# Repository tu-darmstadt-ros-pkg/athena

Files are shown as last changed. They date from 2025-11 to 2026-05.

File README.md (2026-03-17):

# Athena

Picture of the Athena robot with four reconfigurable flippers and a 7-degree-of-freedom manipulator arm inspecting an object.

> [!note]
> This repository is still being filled.
> Lessons learned will be added soon.
> New data will be followed by a new release, so you can just watch for releases.

This repository documents the Athena rescue robot.
All required CAD and KiCAD files are available here for your reference and inspiration.
Copyright remains with the individual contributors, and commercial use is not permitted.

Athena was designed as a research robot for student projects on obstacle traversal and manipulation in rough terrain.
A whole-body crawler design enables the robot to traverse unstructured grounds without the risk of getting stuck, and
the four reconfigurable flippers enable Athena to adapt to the terrain and overcome steps of up to 41cm.
The large manipulator has a reach of up to 1.54 meters and can lift up to 2.9 kilograms at full extension and 7.2
kilograms at 0.5 meters.
With 7 degrees of freedom and 4 continuous joints with slip rings, it is extremely versatile and well-suited for
autonomous manipulation.

The environment perception modules consisting of a Livox MID-360, an Orbbec Astra Stereo S U 3 RGBD camera, and a 240°
FOV wide-angle camera enable comprehensive colored 3D environment perception.



The FOV of the individual sensors of the environment perception module

## Paper

You can find the [preprint here](https://arxiv.org/abs/2602.19898). Please cite as
```
@INPROCEEDINGS{fabian2025athena,
  author={Fabian, Stefan and Schmidt, Aljoscha and Süß, Jonas and Dishant and Oza, Aum and Von Stryk, Oskar},
  booktitle={2025 IEEE International Symposium on Safety Security Rescue Robotics (SSRR)}, 
  title={Athena: An Autonomous Open-Hardware Tracked Rescue Robot Platform}, 
  year={2025},
  pages={166-171},
  doi={10.1109/SSRR68451.2025.11391264}}
```

## CAD

The [CAD](CAD) folder contains all CAD data as Fusion archive for editing and alternatively also as STEP.
Please note that the belts are mostly visual only, and the actual belt lengths are not reflected in the model.

## Electronics

In the [electronics](electronics) folder, the custom PCBs used to distribute power and ensure safety during operation can be found.

## Remote E-Stop

The source code and bill of materials for the ~80€ remote e-stop can be found in [E-Stop](E-Stop).
This ESP32-based remote E-Stop transmits its state over BLE, ESP-NOW and LoRa for high reliability and low triggering times of up (or down) to 10ms.

## Stats

| | |
|-|-|
| Max Speed | 1.5m/s |
| Max Step Height | 41cm |
| Max manipulator reach | 1.54m  |
| Max payload @0.5m | 7.2kg  |
| Max payload @1m | 4.8kg  |
| Max payload @1.54m | 2.9kg  |

## Software

* **Motor Driver**: [athena_motor_driver](https://github.com/tu-darmstadt-ros-pkg/athena_motor_driver) provides firmware for the Teensy and ROS driver to torque-control the Unitree A1 motors. 

## Pictures

The robot Athena on the maximum step height that was tested at 41cm
<br/>
The robot Athena on 45 degree industrial metal stairs.

The robot Athena lifting a gallon and multiple water bottles totaling about 7.2kg

## Lessons learned

* [Drive](LESSONS_LEARNED_DRIVE.md)

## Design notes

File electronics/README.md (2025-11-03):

## Athena electronics

This folder contains the KiCad projects and libraries used for the custom PCBs inside Athena.

A detailed documentation for each PCB can be found inside its project folder.

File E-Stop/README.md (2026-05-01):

# ESP32 Remote E-Stop

## Overview

This repository contains the firmware, shared libraries, and ROS 2 interface for a wireless emergency stop built around the Seeed Studio XIAO ESP32S3, but any other ESP32 should work as well.
It delivers a handheld remote that broadcasts hard and soft E-Stop signals, a receiver that drives the physical safety relay, and an optional deadman switch that can be used for dangerous hardware experiments.
All nodes share a common communication stack that uses ESP-NOW and BLE for redundant, low-latency signaling.

>[!NOTE]
> This library uses [CrossTalk](https://github.com/StefanFabian/crosstalk) for host to serial communication.

## Highlights

- Dual-channel wireless transport (ESP-NOW, BLE)
- Independently latched hard E-Stop and soft E-Stop states.
- Optional deadman transmitter that triggers the hard E-Stop while enabled and not pressed and will only release while held down.
- SH1106 OLED UI on the remote with connectivity status, E-Stop indicators, and battery level.
- ROS 2 interface package for logging, visualization, and software integration with robots or tooling.

## How it works

### Components

- **Remote handset (`esp32_estop_sender_firmware`)** – Hosts the physical E-Stop, soft E-Stop, and release buttons, reads the battery voltage, and pushes state updates through `CommInterface`.
- **Receiver (`esp32_estop_receiver_firmware`)** – Listens as the Bluetooth server and ESP-Now peer, merges wireless channels, asserts the relay output on `D3`, and publishes telemetry over USB using the lightweight [CrossTalk](https://github.com/StefanFabian/crosstalk) protocol.
- **Deadman transmitter (`esp32_deadman_sender_firmware`)** _(optional)_ – Sends "active" and "triggered" states via `DeadmanCommInterface`, allowing a foot pedal or lanyard to feed into the receiver.
- **ROS 2 interface (`esp32_estop_ros` + `esp32_estop_interface`)** – Wraps the CrossTalk datastream in ROS 2 messages (`CommStatus.msg`) and exposes a `SetEnabled` service to bypass the receiver output during testing.
- **Shared firmware library (`esp32_estop_firmware_common`)** – Abstracts the radios, handles property replication, and centralizes MAC configuration inside `include/comm_interface.h`.

### Communication pipeline

1. The remote handset runs `CommInterface` in _client_ mode. Each button state is latched locally and shipped via ESP-NOW datagrams and BLE characteristics.
2. The receiver instances `CommInterface` in _server_ mode. On every update, it reads the newest packet from each transport, chooses the freshest data, and drives the relay output low (active) or high (released).
3. The optional deadman transmitter mirrors the pattern with `DeadmanCommInterface` and is OR'd into the receiver logic, so either the handheld or the deadman can trip the system.
4. Telemetry such as RSSI, link state, battery percentage, and message age are streamed to ROS 2 or any host that speaks CrossTalk over USB.

### Safety logic

- Hard E-Stop is asserted if **any** transport reports an active state or if an active deadman transmitter sees a trigger event.
- Soft E-Stop is tracked separately and can be leveraged by higher-level controllers for graceful deceleration.
- The receiver defaults to the safe state (output asserted) if no valid packets arrive within ~500 ms for the hard E-Stop.

## Hardware

### Bill of materials

| Name | Count | Url | Price | Description |
| --- | ----- | --- | --- | --- |
| Seeed XIAO ESP32S3 | 2 | <https://www.seeedstudio.com/Wio-SX1262-with-XIAO-ESP32S3-p-5982.html> | 10€ | Sender and Receiver ESP with BLE, ESP NOW. Any other ESP32 with sufficient PINs should work as well. |
| Joy-it SBC-OLED01.3 | 1 | <https://www.conrad.de/de/p/joy-it-sbc-oled01-3-display-modul-3-3-cm-1-3-zoll-128-x-64-pixel-passend-fuer-entwicklungskits-arduino-raspberry-pi-2619578.html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> | 9€ | Any 128x64 display supported by U8g2lib can be used without code modification. |
| TRU COMPONENTS Not-Aus-Schalter 3 A | 1 | <https://www.conrad.de/de/p/tru-components-not-aus-schalter-3-a-1-oeffner-ip65-1-st-2304759.html> | 14€ | |
| Samsung ICR18650 | 1 | <https://www.conrad.de/de/p/samsung-icr18650-spezial-akku-18650-kabel-li-ion-3-7-v-2600-mah-251024.html> | 9€ | Any Li-Ion should do. Other types have to be compatible with the ESP and might require a different charging board. |
| USB-C Charging Board | 1 | <https://www.amazon.de/dp/B07XG5F9T3?ref=ppx_yo2ov_dt_b_fed_asin_title> | 8€ (for 10) | Has to be compatible with battery. Note that they do not work with some smart USB-C chargers. |
| Button | 2 | <https://www.roboter-bausatz.de/p/drucktaster-button-schalter-rot-12mm-250v-1a> | 1€ | Any button should do. One for Soft E-Stop and one to release the E-Stops. |
| On-Off Switch | 1 | <https://www.conrad.com/en/p/tru-components-1587504-toggle-switch-tc-r13-66a3-02-250-v-ac-6-a-1-x-off-on-latch-1-pc-s-1587504.html> | 2€ | To toggle power from battery. |
| JST XT Connectors | Kit | <https://www.amazon.de/YIXISI-Stecker-Weiblich-Adapter-M%C3%A4nnlich/dp/B082ZLYRRN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> | 8€ | Suggested connectors to connect ESP to buttons, battery and display. |
| Breadboard | 1 | <https://www.reichelt.com/de/en/shop/product/breadboard_laminated_paper_50x100_mm-8268> | 1€ | To mount ESP32 and connectors, as well as display. |
| PETG Filament | 1 | - | 10€ | |
| **Total Cost** | | | 83€ | |

### ESP 32

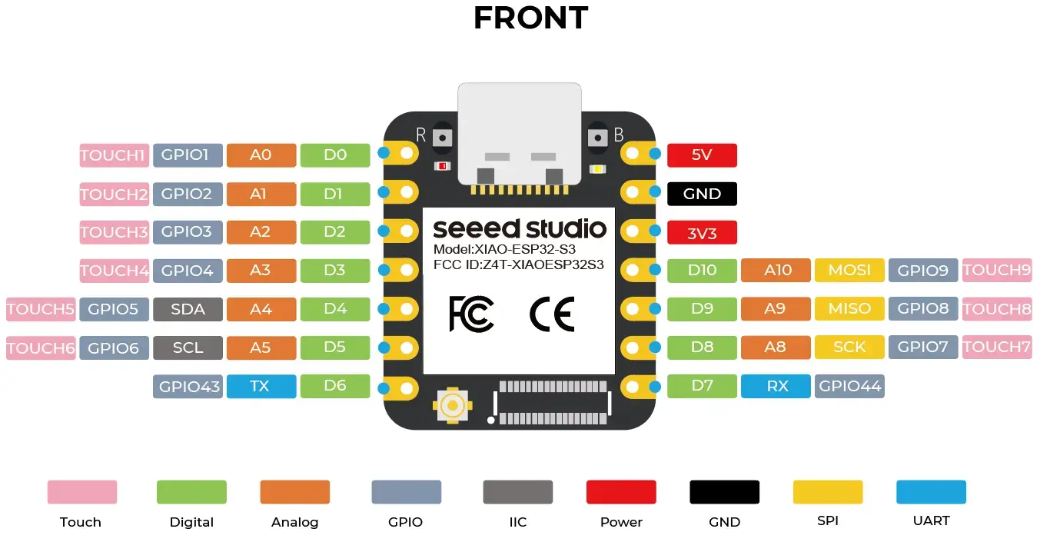
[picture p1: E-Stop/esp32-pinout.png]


#### Sender

| Pin | Function |
| --- | --- |
| D0 | _Unused_ |
| D1 | E-Stop button |
| D2 | Soft E-Stop button |
| A3 | Battery with voltage divider |
| D4, D5, D6  | Display |
| D7 | Release button |

#### Receiver

| Pin | Function |
| --- | --- |
| D3  | Low if E-Stop active, High otherwise |

### Assembly notes

- Power the receiver through the USB-C port
- The remote is powered using a battery after the separate charging board, feed the battery voltage also to `A3` using a same ratio voltage divider (e.g. 100k & 100k).
- The receiver output is an active-low digital pin; use it to drive a safety relay coil, optocoupler, or logic-level input that enforces the actual stop.

## Repository layout

| Directory | Description |
| --- | --- |
| `esp32_estop_sender_firmware/` | PlatformIO project for the handheld remote with OLED UI. |
| `esp32_estop_receiver_firmware/` | PlatformIO project for the base station / relay driver. |
| `esp32_deadman_sender_firmware/` | PlatformIO project for the optional deadman switch node. |
| `esp32_estop_firmware_common/` | Shared library with BLE, ESP-NOW, and CrossTalk helpers. |
| `esp32_estop_interface/` | ROS 2 interface definitions (messages & services). |
| `esp32_estop_ros/` | ROS 2 node that bridges the receiver to the middleware. |

## Getting started

1. **Install PlatformIO** – Either use the VS Code extension or install the CLI (`pip install platformio`).
2. **Clone the repo** – Keep the subdirectories intact so local `lib_deps` references resolve correctly.
3. **Connect the boards** – Plug each XIAO ESP32S3 via USB. The provided `platformio.ini` files expect `/dev/tty_estop_sender`, `/dev/tty_estop_receiver`, and `/dev/tty_estop_deadman_switch`; adjust them or create udev symlinks accordingly.
4. **Configure peer addresses and other settings** – See the next section to point each device at the correct MAC addresses.
5. **Build & flash** – From the respective project folder run `pio run -t upload` (or use the PlatformIO VS Code UI). Repeat for the sender, receiver, and optional deadman switch.
6. **Monitor serial output** – Use `pio device monitor` to confirm link status, RSSI, and the printed MAC addresses during bring-up.

## Configuring peer addresses

All peer MAC addresses, as well as all other relevant configuration live in `esp32_estop_firmware_common/include/config.h`:

- `RECEIVER_PEER_INFO` – The addresses for the receiver on the robot (ESP-NOW + BLE).
- `SENDER_PEER_INFO` – The remote sender's addresses.
- `DEADMAN_PEER_INFO` – The addresses for the optional deadman transmitter.

Each `CommPeerInfo` holds two 6-byte values: the ESP-NOW MAC and the BLE MAC. On the ESP32, the BLE address is typically the ESP-NOW/Wi-Fi address plus one in the least-significant byte. To adapt the system to your own hardware:

1. Flash a board with any of the firmware projects and open the serial monitor. During boot, the firmware prints the local BLE address, e.g.:

   ```text
   BLE Device initialized with address: D8:3B:DA:73:E4:30
   ```

2. Record the ESP-NOW address (`WiFi.macAddress()` if you need to query it manually) and the BLE address for each physical unit.
3. Update the corresponding `CommPeerInfo` constants in `comm_interface.h`. Keep the BLE entry consistent with the ESP-NOW address + 1 if you follow the default convention.
4. Rebuild and flash all nodes so they carry the same lookup table. A mismatch here is the most common cause of "stuck in Connecting..." on the OLED.

## Adapting to your platform

- **Different boards** – Change the `board` field in each `platformio.ini` and adjust the pin mappings to match your target carrier. The shared library is agnostic to the MCU as long as the underlying Arduino core provides ESP-NOW, NimBLE, and RadioLib support.
- **Custom user interface** – The OLED rendering lives in `esp32_estop_sender_firmware/src/main.cpp`; swap in your display driver or button layout without touching the transport layer.
- **Integrating with other controllers** – Consume the USB CrossTalk stream directly or extend the ROS 2 node (`esp32_estop_ros/src/receiver_interface_node.cpp`) to publish additional diagnostics.

## Using the system

1. Power the receiver and ensure the relay output is wired to your safety circuit.
2. Power the remote handset; the OLED shows boot progress, then "Connecting..." until at least one transport is linked.
3. Once connected, the display reports RSSI for BLE and ESP-NOW. The top banner changes to "E-Stop Active" until you press the physical release button.
4. Pressing the hard E-Stop latches the state on every transport. The receiver LED goes LOW and the relay remains asserted until the release sequence completes.
5. If the deadman transmitter is enabled, releasing its button/pedal or hitting the panic trigger instantly asserts the hard E-Stop.
6. The ROS 2 node can be launched to visualize link quality and toggle the `SetEnabled` service to disable the receiver and always enable power if needed (Note that this is dangerous!).

## Troubleshooting tips

- **No connection** – Double-check that the MAC pairs in `comm_interface.h` mirror each device’s printed addresses. A single byte mismatch prevents BLE pairing and ESP-NOW peering.
- **Relay stuck active** – Inspect the `last_received_message_age_ms` field from `CommStatus` via USB; values > 300 indicate packet loss that forces the receiver into the safe state.
- **Deadman not seen** – Verify it is enabled (LED on `D1`) and that its peer info is aligned with the receiver’s `DEADMAN_PEER_INFO` entry.

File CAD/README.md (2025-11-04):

## ATHENA CAD design

This directory contains the CAD files for the Rescue Robot ATHENA. The accompanying documentation outlines each component, its material specification, and the recommended manufacturing process.

The provided CAD model is compatible with Autodesk Fusion 360, and all components are integrated within a single comprehensive assembly file.

**Important** Before importing the model into Fusion 360, ensure that a dedicated folder is created for the project files.

## CAD Description

The primary file, main_assembly, represents the complete mechanical assembly of ATHENA. It includes all sub-assemblies and defines their kinematic and structural relationships.

Both the Flipper and Arm sub-assemblies are fully articulated within the model. They can be repositioned interactively and will automatically return to their defined resting configurations.

ATHENA consists of the following major sub-assemblies:

- sub_assembly_chassis: Composed of bonded and fastened carbon fiber composite (CFK) panels forming the primary load-bearing chassis of the robot.

- four sub_assembly_tracked_drive: Four identical tracked drive units, each integrating a drive motor, drive pulley, and flipper sub-assembly.

- two sub_assembly_battery_box: Two identical removable battery modules, each designed to accommodate a pair of 4S LiPo batteries for modular power management.

- assembly_arm_7_DoF: A 7-DoF manipulator assembly. Each joint includes predefined motion constraints, allowing spatial motion simulation and evaluation of various operational configurations.

## ATHENA Parts, Materials & Manufacturing Specification

This section lists all mechanical components of ATHENA, organized by sub-assembly. Each table specifies the part name, material, recommended manufacturing process, and additional notes.

---

## 1. Sub-Assembly: Chassis

| Part Name / ID | Material | Manufacturing Process | Notes / Remarks |
|---|---|---|---|
| base_plate | Aluminium 7075 | Laser / Plasma cutting | - |
| front_plate x2 | CFK | CNC milling / Waterjet cutting | Load bearing part, fibre arrangement should be considered |
| top_plate | CFK | CNC milling / Waterjet cutting | Load bearing part, fibre arrangement should be considered |
| side_plate | CFK | CNC milling / Waterjet cutting | Load bearing part, fibre arrangement should be considered |
| main_track_holder| CFK | CNC milling / Waterjet cutting | Load bearing part, fibre arrangement should be considered |
| CFK_angles x12 | CFK | COTS | Cut to required lengths |
| battery_box_rails| PETG | 3D printed | - |
| Flipper_motor_holder| Stainless Steel 316L| Sheet metal bending | - |
| ball_bearin_flange_20x32x7 x4| Steel | COTS | - | 
| main_track_holder_cover | GFK and PETG | Hand laminated / 3D printed| - |
| U_profile | Aluminium| COTS | - |
| M3_nut_holder  | PETG | 3D printed | - |
| Electronics holders | PETG| 3D printed | - |
| Carry_Reinforcement x4 | Steel | Laser cut | - |
| battery_box_end_plate x2 | PETG | 3D printed | - |
| sensor holders | PETG | 3D printed | - |
| flipper_motors x4 |  - | COTS | Part number: H54p-200_M54P-060 |

> **Notes:** The chassis is primarily composed of CFK components bonded and fastened to form the load-bearing frame. Maintain tight tolerances and ensure adhesive joints are properly cured. COTS: Commercial Off-The-Shelf

---

## 2. Sub-Assembly: Tracked Drive (x4)

| Part Name / ID | Material | Manufacturing Process | Notes / Remarks |
|---|---|---|---|
| Unitree A1 motor | - | COTS | [Link](https://www.unitree.com/a1/motor) |
| motor_axle_connector | Stainless Steel| CNC machined | Use high strength Loctite when mounting |
| drive_shaft | Steel | CNC machined (COTS)| Part number: KZAC20-180-NA6-NB6-TA63-KA8-HA30-KB86-HB30-KC120-HC60  [Link](https://de.misumi-ec.com/vona2/detail/110300098640/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) |
| shaft _keyway_KEG6-30| Steel | COTS | Part number: KEG6-60  [Link](https://de.misumi-ec.com/vona2/detail/110300253770/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) |
| shaft_keyway_KES6-30 x2| Steel | COTS | Part number: KES6-30 [Link](https://de.misumi-ec.com/vona2/detail/110300253770/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) |
| drive_wheel | PETG | 3D printed | Minimun 6 parameters while printing to maintain a rigid structure |
| WheelSpacer | PETG | 3D printed | - |
| FlipperSpacer  | PETG | 3D printed | - |
| ballbearing_20x42x16 | Steel | COTS | - |
| toothed_belt_pulley_48_flipper | Aluminium 7075 | CNC machined  | - |
| geared_pulley_24 | Aluminium 7075 | CNC machined | - |
| flipper_base_plate_inside | CFK | CNC machined | Load bearing part, correct fibre arrangement should be considered |
| flipper_base_plate_outside| CFK | CNC machined | Load bearing part, correct fibre arrangement should be considered |
| flippersicherung | Aluminium | Lasercut | |
|  shaft_collar_SCCJ20-6 | Steel | COTS | Part number: SCCJ20-6 [Link](https://de.misumi-ec.com/vona2/detail/110302636320/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)|
| belt_pulley_bottom | PETG and Stainless Steel 316L | 3d printed and laser cut | Two laser cut steel plates screwed and sandwiched between three 3D-printed parts |
| belt_pulley_top | PETG | 3D printed | Minimun 6 parameters while printing to maintain rigid structure |
| spacer_ARU-340 x8 | Stainless Steel | COTS | Part number: ARU-340 [Link](https://de.misumi-ec.com/vona2/detail/221006202465/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) |
| flipper_small_wheel x5| PETG | 3D printed | - |
| ballbearing_6x17x6 x10 | Steel | COTS | For flipper small wheel |
| ballbaering_flange_20x32x7 | Steel | COTS | - |
| ballbearing_flange_8x14x4 x2 | Steel | COTS | - |
| wheel spacers x3 | PETG | 3D printed | - |
| shaft_SFHRW8-49-M6-N6 | Steel | COTS | Part number: SFHRW8-49-M6-N6 [Link](https://de.misumi-ec.com/vona2/detail/110300089020/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) |
| main_track | PU with Steel reinforcement | COTS | Custom made [Link](https://www.z24.de/a/40114-zahnriemen-fuer-waschanlagen?zugtraeger=1&profil=2&quantity=1) |
| profile_mount_main_track x104| Steel | CNC machined | - |
| profileP75 x104| PT-Flex 75 | Hand Cast | Reinforced with 3D printed skeleton structure |
| flipperbelt x4 | PU with Steel reinforcement | COTS | Custom made [Link](https://www.z24.de/a/40114-zahnriemen-fuer-waschanlagen?zugtraeger=1&profil=2&quantity=1) |
| profile_mount_flipper x144 | Steel | CNC machined  | - |
| profil_flipper x144 | PT-Flex 75 | Hand Cast  | Reinforced with laser cut steel inserts |

> **Notes:** Each tracked drive unit is identical and integrates a drive motor, drive pulley, and flipper linkage. The flipper assembly interfaces directly with the tracked drive unit. Components must be lightweight yet rigid to withstand dynamic loads.

---

## 3. Sub-Assembly: Battery Box (x2)

| Part Name / ID | Material | Manufacturing Process | Notes / Remarks |
|---|---|---|---|
| battery_box | PETG | 3D printed | Support structure neccessary while printing |
| battery_box_front_plate | CFK | CNC machined/waterjet cutting | |
| latch_C-10-2 x2| Brass | COTS | Part number: C-10-2 [Link](https://de.misumi-ec.com/vona2/detail/221004914126/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) |
| battery x2 | - | COTS | Recommended: LiPo 4S, 25C, 6750 mAh |
| XT60E-F x2 | Plastic/Copper | COTS | May be replaced in fure iteration |

> **Notes:** Each battery box houses two 4S LiPo batteries and is designed for quick replacement. Use heat-resistant materials and ensure electrical insulation integrity.

---

## 4. Sub-Assembly: Arm (7-DoF Manipulator)

| Part Name / ID | Material | Manufacturing Process | Notes / Remarks |
|---|---|---|---|
| Dynamixel H54P-200_M54P-060 x3| - | COTS | [Link](https://emanual.robotis.com/docs/en/dxl/p/ph54-200-s500-r/) |
| Dynamixel H54P-100_M54P-040 x2| - | COTS | [Link](https://emanual.robotis.com/docs/en/dxl/p/ph54-100-s500-r/) |
| Dynamixel H42P-020_M42P-020 x2| - | COTS | [Link](https://emanual.robotis.com/docs/en/dxl/p/ph42-020-s300-r/) |
| FRP54-H440_ASM  | - | COTS | - |
| FRP54-I110K x2  | - | COTS | [Link](https://en.robotis.com/shop_en/item.php?it_id=902-0082-000) | 
| FRP42-I110K | - | COTS | [Link](https://en.robotis.com/shop_en/item.php?it_id=902-0083-000) |
| FRP54-H221K | - | COTS | [Link](https://en.robotis.com/shop_en/item.php?it_id=903-0223-101) |
| FRP42-H221K | - | COTS | [Link](https://en.robotis.com/shop_en/item.php?it_id=903-0237-101)
| roll_0_shaft | Aluminium 7075 | CNC turning  | Tolerances for Press fit |
| ballbearing_25x52x18 | Steel | COTS | - |
| ballbearing_housing | Aluminium 7075 | CNC machined | Tolerances for Press fit |
| slipring_pancake | - | COTS | Custom hardware |
| manipulator_base_plate | Aluminium 7075 | CNC machined | - |
| base_plate | Aluminium | Laser cut | - |
| angle_base_plate x4| Aluminium 7075 | CNC machined | - |
| base_link_joint| Aluminium 7075 | Sheet metal fabrication | - |
| LEDsHolder x2  | PETG | 3D printed | - |
| holders | PETG | 3D printed | - |
| H54_shaft_square x2 | Aluminium 7075 | CNC turning | - |
| slipring_12_way_10A/250V x3| - | COTS | - |
| motor_CFK_tube_connector x2| Aluminium 7075 | CNC machined | - |
| 6058_CFK_round_tube x2 | CFK  | CNC machined  | - |
| ballbearing_hk60 | Steel | COTS | - |
| ballbearingHolder | PETG | 3D printed | - |
| metal_connector_nut_holder x2 | PETG | 3D printed | - |
| Pitch_3_motor_connector | Titanium | SLS 3D printed | Metal tends to shrink during 3D printing |
| Pitch_5_motor_connector | Titanium | SLS 3D printed | Metal tends to shrink during 3D printing |
| H42_shaft | Steel | CNC turning | - |
| sensor_holder  | Steel | Laser cut | - |
| Sensor_torque_ATI-9105-TW-MINI45-E | - | COTS | [Link](https://www.ati-ia.com/products/ft/ft_models.aspx?id=mini45) |
| gripper_holder | PETG | 3D printed | Minimum 6 parameteres while printing and 50% infill |
| RH-P12-RN | - | COTS | [Link](https://emanual.robotis.com/docs/en/platform/rh_p12_rn/), a self developed gripper module will be implemented in a future iteration |
| gripper module holders | PETG | 3D printed | - |

> **Notes:** Each joint includes predefined angular limits and housing components. Consider mass balancing and precision machining for smooth motion and accuracy.

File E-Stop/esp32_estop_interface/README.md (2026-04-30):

# esp32_estop_interface

Messages for the esp32 based E-Stop ROS interface.

### Messages

| Type | Description |
| --- | --- |
|  |  |

### Services

| Type | Description |
| --- | --- |
|  |  |

### Actions

| Type | Description |
| --- | --- |
|  |  |

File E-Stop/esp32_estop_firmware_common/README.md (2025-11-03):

# My PlatformIO Library

## Overview
My PlatformIO Library is a shared common library designed for use in both sender and receiver projects. It provides essential functionalities that can be utilized across different applications.

## Features
- Easy integration with PlatformIO projects.
- Supports Arduino framework.
- Compatible with multiple platforms including ESP32 and Atmel AVR.

## Installation
To install the library, add the following line to your `platformio.ini` file:

```
lib_deps = yourusername/my-platformio-library
```

## Usage
Include the library in your project by adding the following line to your source files:

```cpp
#include <MyLibrary.h>
```

## Example
Here is a simple example of how to use the MyLibrary class:

```cpp
#include <MyLibrary.h>

MyLibrary myLib;

void setup() {
    myLib.begin();
}

void loop() {
    myLib.performTask();
}
```

## Contributing
Contributions are welcome! Please feel free to submit a pull request or open an issue for any suggestions or improvements.

## License
This project is licensed under the MIT License. See the LICENSE file for more details.

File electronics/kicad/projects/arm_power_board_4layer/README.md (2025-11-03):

## General description

This board serves as a carrier for the H60SB0A050NRDC DC-DC converter which is used to power the robot arm and the Wi-Fi access point.

## Connections

There is a single 33V input that connects directly to the output of the Power Distribution Board. There are two high power 24V outputs, one of which connects to the 24V input of the E-Stop board. Another low power 24V output is connected to the Wi-Fi access point.

## Communication interface

The Arm Power Board provides an I2C interface which can be used to program the DC-DC converter and read its voltages and currents. Currently this interface is unused.

## Devices on the PCB

- MIC5282-3.3YMM-TR
	- This is a 3.3V linear regulator that provides a voltage for the power LED and the I2C interface.
- H60SB0A050NRDC
	- This is a powerful programmable DC-DC converter that can output a stable 24V given a wide input range. It is even capable of producing its 24V voltage output given a lower voltage input.
    
## List of components

- Passive components
	- Resistors
		- 1x 1kΩ DIN-0204
		- 3x 4.7kΩ DIN-0204
		- 1x 10kΩ DIN-0204
		- 1x 200kΩ DIN-0204
	- Ceramic capacitors
		- 3x 100pF THT P5.0mm
		- 1x 100nF THT P5.0mm
		- 1x 1uF THT P5.0mm
		- 1x 2.2uF THT P5.0mm
		- 1x 10uF THT P5.0mm
	- Electrolytic capacitors
		- 2x 470uF THT D10.0mm P5.0mm
	- Diodes
		- 1x LED THT D3.0mm

- Connectors
	- 1x Amass XT30U-M
	- 1x Amass XT30U-F
	- 1x JST XH B2B XH-A
	- 1x JST XH B4B XH-A

- ICs
	- 1x MIC5282-3.3YMM-TR

- Other devices
	- 1x H60SB0A050NRDC

## Note

This is the only PCB currently inside the robot that still belongs to the first generation of PCBs which used THT components.

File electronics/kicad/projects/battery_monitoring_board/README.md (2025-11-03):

## General description

This PCB is used to monitor the cell voltages of two 4s LiPo batteries connected in series. This is done using an 8-channel analog digital converter which connects to each cell via a voltage divider.

## Connections

There is a 5V power input that connects to the 5V output from the Power Distribution Board. The power input is forwarded to an output connector on the PCB that allows daisy-chaining multiple boards.
The cell connectors of the two batteries are connected to the board via two five pin connectors.

## Communication interface

The Battery Monitoring Board provides an SPI interface which allows a microcontroller to read the cell voltage measurements from the analog digital converter. This interface currently connects to the Power Distribution Board.

## Devices on the PCB

- LD1117S33TR
	- This is a linear regulator that produces a 3.3V output from a 5V input. The output is used to power the analog digital converter.
- MCP3208T-CI/SL
	- This is an 8-channel analog digital converter that outputs its measurements via SPI.
    
## List of components

- Passive components
	- Resistors
		- 8x 1kΩ 0805
		- 1x 1kΩ 1206
		- 8x 22kΩ 0805
	- Ceramic capacitors
		- 3x 1uF 0805
		- 1x 10uF 0805
	- Electrolytic capacitors
		- 1x 120uF 6.3x7.7mm
	- Diodes
		- 1x LED 0805

- Connectors
	- 2x JST EH B2B EH-A
	- 3x JST XH B5B XH-A

- ICs
	- 1x LD1117S33TR
	- 1x MCP3208T-CI/SL

## Note

The two battery cell connectors on this PCB are connected in series, so that the highest pin of the first connector is directly connected to the lowest pin of the second connector. It is crucial that the main power connectors of the batteries are also connected in series externally.

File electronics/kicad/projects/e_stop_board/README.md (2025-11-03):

## General description

This PCB serves as an E-Stop that allows the main drive motors, flipper motors and arm motors to be quickly disconnected from power using electronic switches. The E-Stop can be triggered both by a physical switch and a radio remote.

## Connections and E-Stop behavior

There are three power inputs, two receiving power from the output of the Power Distribution Board providing 33V for the main drive motors and flipper motors and another input from the 24V converter for the arm motors. There are seven power outputs which connect to the motors of the robot.
- Four outputs for each of the four main drive motors
- Two outputs for the flipper motors
- One output for the robot arm
When the E-Stop is engaged, all of these outputs will be electronically disconnected from the inputs.
A connector labeled 'E-Stop' connects to the physical E-Stop button. When this button is open, the electronic switches are disabled, cutting power to the motors. Another connector with two pins labeled 'IN' and 'GND' is used to connect to the radio receiver of the remote E-Stop. There are two possible states:
- When the 'IN' pin is pulled to 3.3V relative to 'GND', the remote E-Stop is considered disengaged and the electronic switches are enabled, giving power to the motors. 
- When the 'IN' pin is floating or pulled to 'GND', the remote E-Stop is considered engaged and power is cut.
Alternatively, the remote E-Stop receiver may act as a switch itself. If this is the case, the two pins labeled 'IN -> 3.3V' on the PCB can be bridged which will pull the 'IN' pin to 3.3V unless it is pulled to 'GND' by the remote E-Stop receiver.

**Important:**
If a remote E-Stop is connected, then the pins labeled 'EN_MC' must be bridged using a jumper. If there is no remote E-stop connected, the pins labeled 'V3_3' must be bridged.

## Communication interfaces

The main communication interface of the E-Stop board is the USB connection to the STM32 NUCLEO microcontroller. This interface can be used to read the actual E-Stop state as well as the currents from the inputs to each of the outputs.
The E-Stop board also has interfaces for I2C and SPI, which can be used to communicate with the board using another microcontroller. Currently, these interfaces are unused.

## Devices on the PCB

- STM32 NUCLEO microcontroller
	- This microcontroller reads the state of the remote E-Stop and produces a signal to the switches. It also reads the current through each switch.
- BTH500151LUAAUMA1
	- These are high side power switches, that connect or disconnect the inputs and outputs. They are controlled via a digital signal from the microcontroller and output the current flowing through them using an analog voltage.

## List of components

 - Passive components
	- Resistors
		- 3x 1kΩ 0805
		- 6x 2kΩ 0805
		- 5x 4.7kΩ 0805
		- 1x 100kΩ 0805
	- Ceramic capacitors
		- 2x 1uF 0805
		- 9x 10uF 0805
	- Electrolytic capacitors
		- 1x 68uF Size 6.3x7.7mm
		- 1x 120uF Size 6.3x7.7mm
	- Diodes
		- 2x SL26PL-TP
		- 1x SS12
		- 3x LED 0805
	- Inductors
		- 1x 100uH ASPIAIG-S6055
	
- Connectors
	- 3x Amass XT30U-M
	- 7x Amass XT30U-F
	- 2x JST XH B2B XH-A
	- 1x JST XH B3B XH-A
	- 1x JST XH B5B XH-A

- ICs
	- 6x BTH500151LUAAUMA1
	- 1x LM2594MX-5.0/NOPB

- Other devices
	- STM32 NUCLEO-L432KC

## Note

This documentation refers to the second generation E-Stop board.

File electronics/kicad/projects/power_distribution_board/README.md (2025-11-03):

Important: Read section 'Caveats' below before assembling!
## General description

The Power Distribution Board (PDB) is the main PCB inside the robot and has several functions:
1. It acts as a global power switch, connecting to the physical power button to turn the entire system on or off
2. It automatically selects from one of three available power sources to power the system: two 33V batteries and a 24V power supply
3. It distributes power to the system, forwarding the input from the selected power source to other components inside the robot and additionally providing 5V and 12V power outputs through internal voltage converters
4. It monitors input source and outputs bus voltages, as well as the currents from the two batteries
5. It implements battery safety features such as cell undervoltage protection

## Connections

The PDB has two power inputs labeled BAT A and BAT B which each connect to a 33V battery and a third input labeled EXT which connects to an external 24V power supply. 
There are four main power outputs labeled OUT:
- Two of them connect to the E-Stop board, to provide power to the main drive motors and flipper motors.
- One connects to a DC-DC converter, which provides 24V for the robot arm, Wi-Fi access point and LiDARs.
- One connects to a DC-DC converter, which provides 19V for the two PCs.
A power output labeled CAP should be connected to a large bulk capacitor, which stabilizes the power bus and prevents voltage drops during switching events.
Additionally, there are four 5V outputs and three 12V outputs available. The 5V outputs power the two battery monitoring PCBs and the LED on the physical power switch. The 12V outputs power the Ethernet switch inside the robot.
The PDB connects to a physical latching power button, through a connector labeled SW HS. Closing or opening this switch turns the entire robot on or off. A second connector labeled SW LS is also available to connect the separate logic ground plane to global ground. This switch is usually just bridged directly in normal operation.

## Communication interfaces

The PDB has four communication interfaces available. The most important one is the USB connection to the Teensy 4.0 which is used to monitor the PDB using a PC inside the robot. There are also I2C, SPI and UART interfaces available. The SPI interface is currently used to communicate with two battery monitoring PCBs. Their CS pins are currently mapped to the RX and TX pins of the UART interface.

## Devices on the PCB

There are several devices and ICs used on the PDB. Here is a brief description of their functions:

- Teensy4.0 microcontroller
	- This microcontroller is the heart of the PDB, implementing the logic for source selection and switching, as well as monitoring the functions of the PDB.
- ACS72981ELRATR-200U3
	- These ICs measure the currents from the two batteries and report them to the Teensy4.0 microcontroller.
- LTC7001IMSE-TRPBF
	- These are isolated gate driver modules, used to drive the three pairs of common-source n-MOSFETS which connect the input sources to the output power bus. They are controlled via three separate enable signals from the microcontroller.
- LM2594MX-5.0/NOPB
	- This is a buck converter, converting the 33V or 24V from the input to 5V for powering the Teensy4.0 microcontroller.
- LM2594MX-12.0/NOPB
	- This buck converter provides 12V for powering the LTC7001IMSE-TRPBF gate drivers.
- RPA50S-4812SWP
	- This is a DC-DC converter providing 12V power output at 50W.
- RPA50S-4805SWP
	- This is a DC-DC converter providing 5V power output at 50W.
    
## List of components

 - Passive components
	- Resistors
		- 3x 100Ω 1206
		- 4x 1kΩ 1206
		- 2x 4.7kΩ 1206
		- 4x 10kΩ 0805
		- 13x 100kΩ 0805
	- Ceramic capacitors
		- 2x 1nF 0805
		- 2x 10nF 0805
		- 3x 100nF 0805
		- 8x 1uF 0805
		- 2x 2.2uF 0805
	- Electrolytic capacitors
		- 2x 68uF Size 6.3x7.7mm
		- 2x 100uF Size 6.3x7.7mm
		- 2x 120uF Size 6.3x7.7mm
	- Diodes
		- 3x SL26PL-TP
		- 4x LED 0805
		- 2x SS12
	- Inductors
		- 2x 100uH ASPIAIG-S6055

- Connectors
	- 3x JST XH B2B XH-A
	- 6x JST EH B2B EH-A
	- 2x JST EH B3B EH-A
	- 1x JST XH B5B XH-A
	- 5x Amass XT30U-F
	- 3x Amass XT60-M

- MOSFETs
	- 6x IRFS4010TRLPBF

- ICs
	- 2x ACS72981ELRATR-200U3
	- 3x LTC7001IMSE-TRPBF
	- 1x LM2594MX-5.0/NOPB
	- 1x LM2594MX-12.0/NOPB

- Other devices
	- 1x RPA50S-4812SWP
	- 1x RPA50S-4805SWP
	- 1x Teensy4.0

## Caveats

For the current version of the firmware on the Teensy4.0 microcontroller to work properly, two pairs of pins on the microcontroller must be connected together using external wires:
1. Connect pins 8 and 28.
2. Connect pins 9 and 27.
Pins 8 and 9 are connected through the PCB to the current sensing ICs which measure the battery currents. Unfortunately, these pins do not support reading the analog voltages generated by the ICs. Therefore they must be connected to pins 28 and 27 which do support analog inputs.

The following resistors should NOT be soldered to the PCB for normal operation:
- R3
- R6
- R9
- R18
- R19
- R25
These resistors can be used to modify the voltages on the gates of the n-MOSFETs for testing purposes. For normal operation, simply leave the solder pads of these resistors open and unconnected.

The UART interface is currently non-functional, as the RX and TX pins are connected to the CS pins of two external battery monitoring PCBs that communicate with the PDB via SPI.

## Note

This documentation refers to the second generation Power Distribution Board.

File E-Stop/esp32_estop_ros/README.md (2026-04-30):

# esp32_estop_ros

Server node to enable control and publish information from E-Stop receiver to ROS 2.

- [receiver_interface_node](#receiver_interface_node)

## `receiver_interface_node`

### Subscribed Topics

| Topic | Type | Description |
| --- | --- | --- |
|  |  |  |

### Published Topics

| Topic | Type | Description |
| --- | --- | --- |
|  |  |  |

### Services

| Service | Type | Description |
| --- | --- | --- |
|  |  |  |

### Actions

| Action | Type | Description |
| --- | --- | --- |
|  |  |  |

### Parameters

| Parameter | Type | Description |
| --- | --- | --- |
|  |  |  |

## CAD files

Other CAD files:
CAD/assembly_ATHENA v175.step
CAD/assembly_ATHENA v176.f3z

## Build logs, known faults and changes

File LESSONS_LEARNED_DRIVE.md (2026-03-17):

# Lessons Learned - Drive

## Initial Version

Due to time constraints, we, at first, tried 3D-printing track profiles from PETG.
We expected low friction, but the results were even worse than expected.
Even a 10° inclination on plywood is impossible to climb with such profiles.

The first actual version was made from PU with a shore hardness of A70.
We used [Poly 75-70, Polyurethan Shore A70](https://syntecshop.com/de/poly-75-70-polyurethan-shore-a70) and
[PT Flex 70](https://syntecshop.com/de/schnellhartendes-polyurethan-guss-gummi-shore-a-70-pt-flex-70).
They should have the same hardness, but the latter hardens more quickly than the former.
During use, unfortunately, the PT Flex profiles broke much more quickly and often than the Poly 75-70 profiles.
The profiles are made from a 3D printed skeleton for structural strength and an outer shell of PU for grip.

## 2026-03-16

Our new version replaces the 3D-printed skeleton with a steel plate to secure the screws, as the previous revision demonstrated that the profiles were ripping out of the screw holes due to the PETG not being robust enough.
The profiles are now fully PU with only a laser-cut 1mm steel plate to ensure they stay on the belt.
Additionally, we joined the two adjacent flipper profiles into a single part, which is connected at the first few mm, to limit bending when a step lands between the two profiles, improving the ability to climb steps.
The height of the flipper profiles was slightly reduced to ensure they are not in contact with the ground when not traversing unstructured terrain or climbing steps.
This improves the robot's ability to turn on the spot.

>[!NOTE]
> Do not add color to the PU, as this significantly reduces the material's resistance to wear and tear.

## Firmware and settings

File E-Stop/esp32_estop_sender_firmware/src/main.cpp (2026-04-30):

#include "comm_interface.h"
#include "mean_filter.h"
#include <Arduino.h>
#include <elapsedMillis.h>
#include <string>

#include <U8g2lib.h>

constexpr uint8_t ESTOP_PIN = D1;
constexpr uint8_t SOFT_ESTOP_PIN = D2;
constexpr uint8_t RELEASE_PIN = D7;
constexpr uint8_t BATTERY_PIN = A3;
constexpr uint8_t EXPERIMENT_VOLTAGE_INPUT_PIN = A0;
constexpr const char *TITLE = ROBOT_NAME " Remote E-Stop";

TaskHandle_t display_task_handle = nullptr;
SemaphoreHandle_t display_semaphore = nullptr;
U8G2_SH1106_128X64_NONAME_F_HW_I2C display( U8G2_R0, D6, D5, D4 );

CommInterface sender;

elapsedMillis last_print = 0;
elapsedMillis last_status_update_time = 0;
elapsedMillis last_soft_estop_update_time = 0;

bool soft_estop_button_pressed = false;
bool release_button_state = false;
bool display_initialized = false;
MeanFilter<uint32_t, 10> battery_voltage_filter;
bool experiment_running = false;

float readBatteryVoltage()
{
  battery_voltage_filter.addValue( analogRead( BATTERY_PIN ) );
  // Battery voltage is read using a voltage divider. Ratio = 4.127V / 2370
  return battery_voltage_filter.getMean() * ( 4.127f / 2370 );
}

int toBatteryPercentage( float voltage )
{
  // The percentage is calculated based on the voltage range of 3.0V (empty) to 4.2V (full).
  // The formula is: percentage = (voltage - 3.0) / (4.2 - 3.0) * 100
  if ( voltage < 3.0f ) {
    return 0; // Below minimum voltage, return 0%
  }
  if ( voltage > 4.2f ) {
    return 100; // Above maximum voltage, return 100%
  }
  return ( voltage - 3.0f ) / ( 4.2f - 3.0f ) * 100;
}

void drawBootScreen();

void updateDisplayTask( void * );

void runExperiment();

void setup()
{
  Serial.begin( 115200 );
  Serial.println( "Starting " ROBOT_NAME " E-Stop Remote..." );
  pinMode( BATTERY_PIN, INPUT );

  if ( display.begin() ) {
    display_initialized = true;
    drawBootScreen();
  } else {
    Serial.println( "Failed to initialize display!" );
  }

  sender.initialize( CommMode::CLIENT, RECEIVER_PEER_INFO );
  sender.setEStopState( true );      // Set E-Stop state to active initially
  sender.setSoftEStopState( false ); // Soft E-Stop is inactive initially

  Serial.println( "CommInterface initialized" );

  // Turn on LED
  pinMode( LED_BUILTIN, OUTPUT );
  digitalWrite( LED_BUILTIN, LOW );

  pinMode( ESTOP_PIN, INPUT_PULLDOWN );
  pinMode( SOFT_ESTOP_PIN, INPUT_PULLDOWN );
  pinMode( RELEASE_PIN, INPUT_PULLDOWN );
  pinMode( EXPERIMENT_VOLTAGE_INPUT_PIN, INPUT );

  soft_estop_button_pressed = digitalRead( SOFT_ESTOP_PIN ) == HIGH;
  release_button_state = digitalRead( RELEASE_PIN ) == HIGH;
  display_semaphore = xSemaphoreCreateMutex();
  xTaskCreatePinnedToCore( updateDisplayTask, "UpdateDisplay", 4096, nullptr, 0,
                           &display_task_handle, 0 );
}

struct DisplayStatus {
  CommStatus comm_status;
  bool estop_active;
  bool soft_estop_active;
} display_status;

constexpr int EXPERIMENT_STEPS = 1000;
struct ExperimentStatus {
  bool held_down = false;
  elapsedMillis held_time;
  int step = 0;
  bool estop_active = true;
  elapsedMillis step_time;
  int durations[EXPERIMENT_STEPS] = {};
  bool printed_results = false;
};

ExperimentStatus experiment_status;
elapsedMillis last_update_display_status;

void updateDisplay();

void updateState();

void loop()
{
  if ( !experiment_running ) {
    updateState();
  } else {
    runExperiment();
  }
  CommStatus status = sender.update();
  if ( last_update_display_status > 50 && xSemaphoreTake( display_semaphore, 10 ) ) {
    last_update_display_status = 0;
    display_status = { status, sender.getEStopState(), sender.getSoftEStopState() };
    xSemaphoreGive( display_semaphore );
  }
  vTaskDelay( 1 / portTICK_PERIOD_MS );
}

void updateState()
{
  // Read E-Stop button state. Here LOW means pressed, HIGH means not pressed
  const bool estop_state = digitalRead( ESTOP_PIN ) == LOW;
  // Read Soft E-Stop button state. Since these close the circuit when pressed, we use HIGH for pressed
  const bool soft_estop_state = digitalRead( SOFT_ESTOP_PIN ) == HIGH;
  // Read Release button state
  const bool last_release_state = release_button_state;
  release_button_state = digitalRead( RELEASE_PIN ) == HIGH;
  const bool release_button_pressed = release_button_state && !last_release_state;
  if ( release_button_pressed && !estop_state && !soft_estop_state ) {
    // If the Release button is pressed (and none of the estops are active), set E-Stop state to inactive
    sender.setEStopState( false );
    sender.setSoftEStopState( false );
    Serial.println( "Release button pressed, E-Stop and Soft E-Stop deactivated." );
  } else {
    // Only allow change to true. For release, we use the Release button
    const bool current_estop_state = sender.getEStopState();
    const bool current_soft_estop_state = sender.getSoftEStopState();
    if ( estop_state != current_estop_state || last_status_update_time > STATUS_UPDATE_INTERVAL_MS ) {
      last_status_update_time = 0;
      sender.setEStopState( sender.getEStopState() || estop_state );
    }
    if ( ( soft_estop_state && soft_estop_state != current_soft_estop_state ) ||
         last_soft_estop_update_time > SOFT_ESTOP_UPDATE_INTERVAL_MS ) {
      last_soft_estop_update_time = 0;
      sender.setSoftEStopState( sender.getSoftEStopState() || soft_estop_state );
    }
    if ( !estop_state && release_button_state && soft_estop_state ) {
      // If E-Stop is inactive and both Release and Soft E-Stop are pressed and held for 3s, start experiment
      if ( !experiment_status.held_down ) {
        experiment_status.held_down = true;
        experiment_status.held_time = 0;
      } else if ( experiment_status.held_time > 3000 && !experiment_running ) {
        uint32_t mv = analogReadMilliVolts( EXPERIMENT_VOLTAGE_INPUT_PIN );
        Serial.println( mv );
        if ( mv > 2000 ) {
          experiment_running = true;
          experiment_status.printed_results = false;
          sender.setEStopState( true );
          experiment_status.estop_active = true;
          experiment_status.step = 0;
          Serial.println( "Experiment started." );
        }
      }
    } else {
      experiment_status.held_down = false;
    }
  }
}

void updateDisplayTask( void * )
{
  while ( true ) {
    if ( !display_initialized ) {
      vTaskDelay( 500 / portTICK_PERIOD_MS );
      continue;
    }
    updateDisplay();
    vTaskDelay( 200 / portTICK_PERIOD_MS );
  }
}

bool first_connect = true;
elapsedMillis last_battery_draw_time = 0;

void drawBatteryLevel()
{
  float voltage = readBatteryVoltage();
  int percentage = toBatteryPercentage( voltage );
  const char *battery_icon = "0";
  if ( percentage >= 90 ) {
    battery_icon = "5"; // Full
  } else if ( percentage >= 70 ) {
    battery_icon = "4"; // High
  } else if ( percentage >= 50 ) {
    battery_icon = "3"; // Medium
  } else if ( percentage >= 30 ) {
    battery_icon = "2"; // Low
  } else if ( percentage >= 10 ) {
    battery_icon = "1"; // Critical
  }
  if ( percentage > 10 || last_battery_draw_time > 1000 ) {
    last_battery_draw_time = 0;
    display.setFont( u8g2_font_battery19_tn );
    display.drawStr( 119, 20, battery_icon );
  }
}

void drawBootScreen()
{
  display.clearBuffer();
  display.setFont( u8g2_font_squeezed_b7_tr );
  display.drawStr( 0, 12, TITLE );
  drawBatteryLevel();
  display.setFont( u8g2_font_logisoso16_tf );
  display.drawStr( 0, 48, "Booting..." );
  display.sendBuffer();
}

void drawCommState( int x, int y, CommState state, int latency_ms, float rssi )
{
  if ( state == CommState::ERROR ) {
    display.drawStr( x, y, "ERROR" );
    return;
  }
  if ( state == CommState::DISCONNECTED ) {
    display.drawStr( x, y, "-" );
    return;
  }
  std::string text;
  if ( latency_ms >= 0 ) {
    text = latency_ms > 999 ? ">999ms" : std::to_string( latency_ms ) + "ms";
    text += "(" + std::to_string( int( rssi ) ) + " dBm)";
  } else {
    text = std::to_string( int( rssi ) ) + " dBm";
  }
  display.drawStr( x, y, text.c_str() );
}

void updateDisplay()
{
  xSemaphoreTake( display_semaphore, portMAX_DELAY );
  DisplayStatus status = display_status;
  xSemaphoreGive( display_semaphore );
  display.clearBuffer();

  if ( experiment_running ) {
    display.setFont( u8g2_font_squeezed_b7_tr );
    display.drawStr( 0, 12, "Running Experiment" );
    display.setFont( u8g2_font_prospero_bold_nbp_tf );
    display.drawStr( 24, 32,
                     ( "Step " + std::to_string( experiment_status.step ) + " / " +
                       std::to_string( EXPERIMENT_STEPS ) )
                         .c_str() );
  } else {
    display.setFont( u8g2_font_squeezed_b7_tr );
    display.drawStr( 0, 12, TITLE );
    drawBatteryLevel();
    if ( first_connect ) {
      if ( status.comm_status.ble_state == CommState::CONNECTED ||
           status.comm_status.esp_now_state == CommState::CONNECTED ) {
        first_connect = false;
      }
      display.setFont( u8g2_font_logisoso16_tf );
      display.drawStr( 0, 48, "Connecting..." );
    } else if ( status.comm_status.ble_state == CommState::DISCONNECTED &&
                status.comm_status.esp_now_state == CommState::DISCONNECTED ) {
      display.setFont( u8g2_font_logisoso16_tf );
      display.drawStr( 0, 48, "Reconnecting..." );
    } else {
      if ( status.estop_active ) {
        display.setFont( u8g2_font_open_iconic_check_2x_t );
        display.drawStr( 0, 35, "B" );
        display.setFont( u8g2_font_prospero_bold_nbp_tf );
        display.drawStr( 24, 32, "E-Stop Active!" );
      } else if ( status.soft_estop_active ) {
        display.setFont( u8g2_font_open_iconic_check_1x_t );
        display.drawStr( 0, 32, "D" );
        display.setFont( u8g2_font_prospero_bold_nbp_tf );
        display.drawStr( 14, 32, "Soft E-Stop Active!" );
      } else {
        display.setFont( u8g2_font_open_iconic_check_2x_t );
        display.drawStr( 0, 35, "@" );
        display.setFont( u8g2_font_prospero_bold_nbp_tf );
        display.drawStr( 24, 32, "E-Stop Inactive" );
      }
    }
  }
  if ( status.comm_status.ble_state != CommState::DISCONNECTED ||
       status.comm_status.esp_now_state != CommState::DISCONNECTED ) {
    display.setFont( u8g2_font_minuteconsole_tr );
    display.drawStr( 2, 48, "BLE" );
    drawCommState( 0, 60, status.comm_status.ble_state, status.comm_status.ble_latency_ms,
                   status.comm_status.ble_rssi );
    display.drawStr( 66, 48, "ESP-NOW" );
    drawCommState( 64, 60, status.comm_status.esp_now_state, status.comm_status.esp_now_latency_ms,
                   status.comm_status.esp_now_rssi );
  }
  display.sendBuffer();
}

void runExperiment()
{
  if ( experiment_status.step >= EXPERIMENT_STEPS ) {
    if ( !experiment_status.printed_results ) {
      experiment_status.printed_results = true;
      experiment_status.step_time = 0;
      xSemaphoreTake( display_semaphore, portMAX_DELAY );
      display.clearBuffer();
      display.setFont( u8g2_font_squeezed_b7_tr );
      display.drawStr( 0, 12, "Results" );
      display.setFont( u8g2_font_prospero_bold_nbp_tf );
      int sum = 0;
      Serial.println( "Experiment durations (s):" );
      for ( int i = 0; i < EXPERIMENT_STEPS; i++ ) {
        Serial.print( experiment_status.durations[i] );
        Serial.print( ", " );
        sum += experiment_status.durations[i] * 10;
      }
      Serial.println();
      int mean = sum / EXPERIMENT_STEPS;
      int var_sum = 0;
      for ( int i = 0; i < EXPERIMENT_STEPS; i++ ) {
        int diff = experiment_status.durations[i] * 10 - mean;
        var_sum += diff * diff;
      }
      float stddev = sqrt( static_cast<float>( var_sum ) / EXPERIMENT_STEPS );
      char buffer[64];
      sprintf( buffer, "Avg: %.1f +- %.1f", mean / 10.0f, stddev / 10.0f );
      display.drawStr( 24, 32, buffer );
      display.sendBuffer();
    }
    if ( experiment_status.step_time > 20000 ) {
      xSemaphoreGive( display_semaphore );
      experiment_running = false;
    }
    return;
  }
  uint32_t val = analogReadMilliVolts( EXPERIMENT_VOLTAGE_INPUT_PIN );
  // Serial.println(val);
  if ( experiment_status.estop_active ) {
    if ( val < 500 ) {
      experiment_status.step_time = 0;
      sender.setEStopState( false );
      last_status_update_time = 0;
      experiment_status.estop_active = false;
    }
  } else if ( val > 1500 ) {
    sender.setEStopState( true );
    last_status_update_time = 0;
    experiment_status.estop_active = true;
    experiment_status.durations[experiment_status.step] = experiment_status.step_time;
    experiment_status.step++;
  }
  if ( last_status_update_time > 50 ) {
    sender.setEStopState( experiment_status.estop_active );
    last_status_update_time = 0;
  }
}

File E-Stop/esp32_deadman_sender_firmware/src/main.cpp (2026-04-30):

#include "deadman_comm_interface.h"
#include <Arduino.h>
#include <elapsedMillis.h>

#define ENABLED_PIN D10
#define DEADMAN_PIN D8
#define PANIC_TRIGGER_PIN D7
#define CONNECTED_LED_PIN D1
#define ACTIVE_LED_PIN D2
#define INACTIVE_LED_PIN D3

DeadmanCommInterface sender;

elapsedMillis last_print = 0;

void setup()
{
  Serial.begin( 115200 );
  Serial.println( "Starting " ROBOT_NAME " Deadman Switch..." );

  sender.initialize( RECEIVER_PEER_INFO );
  sender.setActive( false );
  sender.setTriggered( false );

  Serial.println( "CommInterface initialized" );

  // Turn on LED
  pinMode( LED_BUILTIN, OUTPUT );
  digitalWrite( LED_BUILTIN, LOW );

  pinMode( ENABLED_PIN, INPUT_PULLDOWN );
  pinMode( DEADMAN_PIN, INPUT_PULLDOWN );
  pinMode( PANIC_TRIGGER_PIN, INPUT_PULLDOWN );
  pinMode( INACTIVE_LED_PIN, OUTPUT );
  pinMode( ACTIVE_LED_PIN, OUTPUT );
  pinMode( CONNECTED_LED_PIN, OUTPUT );
  digitalWrite( INACTIVE_LED_PIN, LOW );
  digitalWrite( ACTIVE_LED_PIN, LOW );
  digitalWrite( CONNECTED_LED_PIN, LOW );
}

struct {
  bool enabled;
  bool triggered;
  bool panic_triggered;
} State;

elapsedMillis last_send = 0;

void loop()
{
  const bool enabled_state = digitalRead( ENABLED_PIN ) == HIGH;
  const bool deadman_state = digitalRead( DEADMAN_PIN ) == HIGH;
  const bool panic_trigger_state = digitalRead( PANIC_TRIGGER_PIN ) == HIGH;

  CommStatus status = sender.update();

  if ( status.esp_now_state == CommState::CONNECTED || status.ble_state == CommState::CONNECTED ) {
    digitalWrite( CONNECTED_LED_PIN, HIGH );
  } else {
    digitalWrite( CONNECTED_LED_PIN, LOW );
  }

  if ( enabled_state != State.enabled ) {
    State.enabled = enabled_state;
    sender.setActive( State.enabled );
    if ( State.enabled ) {
      Serial.println( "Deadman Switch Enabled" );
    } else {
      Serial.println( "Deadman Switch Disabled" );
      digitalWrite( INACTIVE_LED_PIN, LOW );
    }
  }
  if ( !State.enabled ) {
    digitalWrite( ACTIVE_LED_PIN, LOW );
    digitalWrite( INACTIVE_LED_PIN, LOW );
    // Send periodic update even if state hasn't changed
    if ( last_send > 100 ) {
      last_send = 0;
      sender.setActive( State.enabled );
    }
  } else {
    const bool triggered = !deadman_state || panic_trigger_state || State.panic_triggered;
    if ( last_send > 100 || triggered != State.triggered ) {
      last_send = 0;
      State.triggered = triggered;
      sender.setTriggered( State.triggered );
      if ( State.triggered ) {
        digitalWrite( ACTIVE_LED_PIN, HIGH );
        digitalWrite( INACTIVE_LED_PIN, LOW );
      } else {
        digitalWrite( ACTIVE_LED_PIN, LOW );
        digitalWrite( INACTIVE_LED_PIN, HIGH );
      }
    }

    if ( panic_trigger_state != State.panic_triggered && State.panic_triggered != deadman_state ) {
      // Can only reset panic trigger if deadman button is also released
      State.panic_triggered = panic_trigger_state;
      if ( State.panic_triggered ) {
        Serial.println( "Panic Triggered" );
      } else {
        Serial.println( "Panic Released" );
      }
    }
  }

  if ( last_print > 2000 ) {
    last_print = 0;
    Serial.printf(
        "Status: ESP-NOW: %s, BLE: %s | Active: %s | Triggered: %s | RSSI: "
        "ESP-NOW: %d, BLE: %d\n",
        status.esp_now_state == CommState::CONNECTED
            ? "Connected"
            : ( status.esp_now_state == CommState::DISCONNECTED ? "Disconnected" : "Error" ),
        status.ble_state == CommState::CONNECTED
            ? "Connected"
            : ( status.ble_state == CommState::DISCONNECTED ? "Disconnected" : "Error" ),
        sender.isActive() ? "true" : "false", sender.isTriggered() ? "true" : "false",
        status.esp_now_rssi, status.ble_rssi );
  }

  // Run this loop every 2ms
  delay( 2 );
}

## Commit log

2025-10-30 Added CAD data.
    [assembly_ATHENA v175.f3z, assembly_ATHENA v175.step]
2025-10-31 Added electronics folder
    [arm_power_board_4layer.kicad_pcb, arm_power_board_4layer.kicad_sch, battery_monitoring_board.kicad_pcb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]
2025-11-03 Added electronics section.
    Added Electronics section to README with PCB details.
2025-11-04 updated CAD
    [assembly_ATHENA v175.f3z, assembly_ATHENA v176.f3z]
2026-01-16 Add software section for motor driver information
    Added a section about the motor driver used for torque control.
2026-03-17 Add lessons learned for drive profile development
    Document lessons learned from initial and updated versions of the drive profiles, including material choices and design improvements.
